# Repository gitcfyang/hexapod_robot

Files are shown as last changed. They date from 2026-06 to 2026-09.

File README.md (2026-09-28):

# Hexapod Robot

六足机器人，基于 Raspberry Pi Pico (RP2040)。18 路数字舵机（2× PCA9685）、
BNO055 IMU 自动调平，支持 ELRS CRSF / PS2 手柄 / USB 三种输入。

## 特性

- 控制循环（默认 100Hz，运行期可调 50~200Hz）+ 实时 IK 解算；四种步态
  （三角 6/8、波纹、波浪）+ 仿生连续变速
- 平衡模式（机身姿态直接控制）+ IMU 姿态补偿自动调平（可选）
- CRSF / PS2 双驱动常编译，`!MODE` 运行时切换，无需焊接插拔；两个驱动共用同一套
  通道与参数（手柄的摇杆/按键在固件里换算到同一套通道号），遥控页 5Hz 实时显示
  协议原值（CRSF 16 通道 172~1811 / PS2 四摇杆 0~255 + 16 按键）
- Betaflight 式「模式」页：解锁/平衡/步态/站立姿态挂在哪个通道、落在哪几档
  （模式矩阵），以及一次性动作用哪组按键（组合键，遥控上按键 = 通道 CH5~CH16），
  全部是运行期参数，`!CFGW` 掉电保持；每行可选「单击触发」（拨一下切换）或按住生效，
  同一套配置对遥控器与手柄都成立 —— 解锁出厂是电平语义（开关拨走即上锁），
  勾上「单击触发」就变回拨一下翻转
- 运动学几何（腿节长度/站高/舵机零位/安装角/机身与足端偏移）是运行期参数，
  网页「几何」页可调，上电时生效
- 电池保护（过压/低压/过放自动断舵机供电）、硬件看门狗、I2C 总线自恢复
- 非易失存储：校准参数（18 路 horn_offset + PWM 周期）存 flash 掉电保持，
  事件日志环形记录（BOOT/电池/校准），`!SAVE` / `!LOG` / `!LOGC`
- 运行时参数：92 项（步态行程/阈值/开关/方向取反/IMU 手感/通道映射/模式矩阵与
  组合键/几何/控制周期/外设所有权与波特率/引脚归属）可在网页或串口在线调整，`!CFG` / `!CFGR` /
  `!CFGW`，改完即生效（几何组例外：重启后生效）、`!CFGW` 存 flash 掉电保持
- 板载预留接口在线可控：直流电机 ×2（仅调速，无方向脚）/ 蜂鸣器 / 双 LED /
  外部 UART0（GP0/GP1）/ 外部 I2C 或 ADC（GP26/27）/ PCA9685 空闲 14 路 PWM，
  串口命令 + 网页「外设」页（外设尚未接线，详见 [STATUS.md](STATUS.md)）
- Betaflight 式「端口」页：一行一组引脚选用途 —— 复用脚（UART0 / 输入 UART1 /
  电机 GP2-3 / 足端检测 GP16-21 / 外部排针 GP26-27）改功能下拉即写参数；
  GP23/24/29 这三脚在板上没往外引（Pico 模块内部分别连着 SMPS 模式 / VBUS 检测 /
  VSYS 检测），页面照常能切输入输出、用 `!GPO` 给电平，但只当调试口用；
  固定脚只读。状态列报引脚此刻的实测电平（`!PORTS` 轮询），
  参数与硬件对不上时看得出来
- TCP/IP 远程访问：串口控制台内置 TCP 桥接（多客户端广播 + 命令反向下发），
  可 headless 运行，配 `tools/tcp_monitor.py` 远程操作
- PCB 设计、Gerber、全项目 BOM、机械 STEP 全部开源（见 [hardware/](hardware/)）

## 快速开始

```bash
cd pico/build && make -j$(nproc)
```

编译产物 `hexapod_pico.uf2` 拖入 Pico 的 USB 盘即烧录；Linux 下可免按键：
`picotool load -f -x build/hexapod_pico.uf2`（运行中的固件会被软复位进 BOOTSEL）。
调试控制台：`python3 tools/serial_console.py`（自动连接、断线重连）。
网页配置台（同一个页面，两种开法）：

**直连 —— 板子插在你自己电脑上，零安装**：Chrome/Edge/Opera 打开
<https://gitcfyang.github.io/hexapod_robot/> → 点「连接」→ 浏览器弹串口选择器选中
Pico，页面直接读写 USB 串口（Web Serial），没有本地服务、不用下载任何东西。
参数/端口/校准/日志都在这一条路上；改动推上 main 后 Pages 自动发布（约 10 分钟生效；
仓库首次要去 Settings → Pages 把 Source 选成 GitHub Actions，一次性）。
**备选：双击本地那份 [index.html](tools/webconfig/index.html)** —— 同一个页面、同样的
功能，不用等发布也不联网，只是得自己把文件拿到手（Chrome 把 `file://` 也当安全上下文，
串口照常可用）。Safari 不支持，Firefox 需 151+；浏览器不给弹串口选择器时换下面「本地服务」那套。
⚠️ **烧固件不在直连里** —— uf2 拖进 Pico 的 USB 盘照旧。

**本地服务 —— 板子插在别的机器上，或要烧固件**：`python3 tools/webconfig/run.py start`
→ 浏览器开 `127.0.0.1:8080`
（同一个脚本还有 `stop`/`restart`/`status`/`logs`，重启＝先终止旧进程再起新的；
它只管这个 HTTP 服务，不碰串口桥。Linux 侧 `tools/webconfig/run.sh start` 是它的包装，
不经脚本直接跑 `python3 tools/webconfig/server.py` 也一样。
跨平台的是 `run.py`（Windows/WSL 同样可用），但串口桥 `serial_console.py` 本身是 Linux-only，
Windows 只适合当浏览器一端、用 VSCode 端口转发连过来。
打开先是**开始页**：只看硬件是否在线、机器人跑的是什么固件，并可一键烧录新固件；
检测到设备后点「连接」才进调试页 —— 状态: 实时电压/I2C/IMU/舵机角度 · 参数按功能
分页（步态/姿态/几何/遥控/模式/电源/平衡/控制/外设/端口）: 滑条改参数并写 flash ·
几何: 腿长/站高/舵机零位/安装角/偏移（重启生效）· 遥控: 输入源切换 +
通道实时显示 · 模式: 解锁/步态/站姿的模式矩阵 + 组合键 + 单击触发 + 实时状态徽标 ·
控制: 舵机供电开关 + 行走/转向/步态/抬腿按钮 + 两块 PCA9685 的
PWM 周期滑条 · 外设: 电机/LED/蜂鸣器/外部 UART/外部 I2C+ADC/空闲 PWM 控制卡 ·
端口: 每对引脚的功能选择（复用脚改用途、GP23/24/29 切输入/输出并给电平、固定脚只读），
外加引脚实测电平 · 校准: 逐舵机定机械中心（选中格子 → 滑条转到中立位 → 设为中心），
再是舵机走查/保存/总线扫描 + 电压标定（万用表实测值 → 分压比）+ IMU 校准
（校准等级显示 / 复位重标）· 日志: 串口日志 + 命令输入；拔 USB、桥接断开或点
「断开连接」都会回到开始页，细节见 [STATUS.md](STATUS.md)）。
连接前可勾「调试时允许遥控器控制」—— 不勾（默认）则调试期间遥控器只上报通道值，
机器人只听网页命令；机器人自己会在失去心跳 6s 后放回遥控器（网页挂了不会锁死）。
远程访问：控制台默认同时开 TCP 桥接（`127.0.0.1:7100`），
另开终端 `python3 tools/tcp_monitor.py` 即可远程收发命令（可多开）。
**网页给别人用**：板子在对方手边，让他开上面那个 Pages 直连页就行（你这边不用做任何事）；
板子插在你这台机器上、要让别的电脑看，才需要下面这套 —— 服务默认只监听 `127.0.0.1`（本机浏览器），要让别的电脑连，
起服务时给监听地址 —— 同一局域网 `run.py start --host 0.0.0.0`，
任何设备开 `http://<这台机器的IP>:8080`；跨网络又不想挂公网，就用 Tailscale
（本机已在跑）等私有网，`run.py start --host <tailnet IP>`，加入同一网络的设备
直接开 `http://100.x.y.z:8080`，两个网卡都不通的路由不会经过它。
⚠️ 这个服务没有鉴权：能连上网页的人就能解锁、驱动 18 路舵机、烧固件。所以
「任何浏览器都能开」的公网隧道要么别开，要么先加鉴权（TODO，见 STATUS）。
（直连那条路不涉及这个问题：页面虽在公网，但只有把板子插在自己电脑上、并在浏览器
弹窗里亲手选中串口的人才能操作它 —— 指令不过任何服务器。）
串口桥（7100）保持只听本机，别跟着放开。

## 硬件概览

- MCU: Pico (RP2040) · 舵机: 18× 双轴数字舵机, 2× PCA9685 · IMU: BNO055 (I²C 0x29)
- 电池: 2S 18650, GP28 ADC2 分压 47/377 (330k+47k)，低压/过压/过放自动断舵机供电（双路AO4407A实现）
  （`batt_check` 参数默认 0，待新板实测分压后启用；分压比可在网页校准页按万用表实测值一键重标）
- 足端微动开关 ×6 · 无源蜂鸣器 · 双 LED · 直流电机 ×2（调速）
- 预留未接线：外部 UART0（GP0/GP1）· 外部 I2C 或 ADC（GP26/27）·
  PCA9685 空闲 14 路 PWM（编号与舵机通道不相交，可与舵机同批输出）
- 完整 GPIO 分布、电池保护分级行为: 见 [STATUS.md](STATUS.md) 硬件章节

## 机架

本项目机架使用 18× **双轴舵机**（STEP 模型见 [hardware/mechanical/](hardware/mechanical/)）。
低成本替代可用 3D 打印方案 [MakeYourPet/hexapod](https://github.com/MakeYourPet/hexapod)
(MIT，MG996R 单轴舵机)：移植本固件只需改腿节长度、舵机零位、安装角等几何参数
（网页「几何」页或 `!CFG`，重启生效，详见 [STATUS.md](STATUS.md)），
IK 与步态算法本身无需修改（同为 3 关节腿）。

## 控制

| 模式 | CH1 | CH2 | CH3 | CH4 | CH5~CH8 |
|---|---|---|---|---|---|
| 正常 | 左右平移 | 前进/后退 | 机身高度 | 原地转向 | 解锁 / 步态 / 站立姿态 / 平衡模式 |
| 平衡 | 机身横滚 | 机身俯仰 | 机身高度 | 机身偏航 | 同上 |

表中 CH1~CH8 是**默认**映射，全部可在网页上改（「遥控」页改摇杆通道、「模式」页改
开关）：摇杆通道填 `0~19`（`!CFG ch_fwd <0-19>`），开关是「通道 + 低/中/高档位」的
模式矩阵。**遥控器与手柄共用这一套** —— 手柄的摇杆与按键先换算成同一套通道号，
再走同一段映射，改完立即生效、`!CFGW` 掉电保持。
每行还能勾「单击触发」：不勾 = 停在激活区间内才生效（解锁出厂如此），
勾上 = 进入区间时动作一次（解锁/平衡翻转，步态/站姿选一次）。手柄的一次性动作
（切步态/站姿、抬腿、急停）在「模式」页的组合键表里，遥控上按键即通道 CH5~CH16。
出厂默认方向取反全 0；若某个方向与手感相反，翻「遥控」页的「方向取反」
（如 `!CFG inv_str 1`），不要改通道号。
输入源由参数 `input_mode` 决定（`!MODE crsf|ps2` 或网页按钮切换，`!CFGW` 掉电保持），
`INPUT_CONTROL_MODE` 只是出厂默认值。PS2 完整按键映射见 STATUS.md。

## 结构

```
hexapod_robot/
├── pico/        # RP2040 固件 (HAL 结构: Inc/Src)
├── tools/       # 串口控制台 serial_console.py (+ TCP 桥接) · IK 仿真 ik_gait_debug.py
│              # webconfig/ 网页配置台 · tcp_monitor.py 远程客户端 · 无硬件测试
├── hardware/    # PCB 设计/机械/BOM (见 hardware/README.md)
├── README.md
└── STATUS.md    # 固件细节: GPIO/参数/步态/调试/电路保护
```

## 状态

> ⚠️ **项目仍在持续开发中，功能和接口可能随时变动。**

## License

固件: GNU GPLv3（见 [LICENSE](LICENSE)）。硬件文件授权另行约定（见 [hardware/README.md](hardware/README.md)）。

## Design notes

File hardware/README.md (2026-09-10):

# 硬件文件

六足机器人的 PCB 设计与机械结构。硬件接口说明见 [../STATUS.md](../STATUS.md) 硬件章节。

## PCB (v2, 2026-09)

- [pcb/source/](pcb/source/) — 立创EDA 专业版工程（原理图 + PCB）
- [pcb/schematic.pdf](pcb/schematic.pdf) — 原理图 PDF（网页可直接预览）
- [pcb/board/gerber/](pcb/board/gerber/) — 打板文件（zip 打包，直接上传嘉立创）
- [pcb/board/assembly/](pcb/board/assembly/) — 贴装 BOM + 坐标文件（SMT 贴片用）

设计要点：2S 18650 直供舵机轨（2× AO4407A 门控，上电默认断电）；VBAT 入口
SMBJ18A + 每颗 MOSFET 两端 SMBJ12A；I2C 总线 TVS + BNO055 stub 串阻 + VDD 限流；
电池分压 330k+47k 入 GP28 ADC2。保护设计背景见 STATUS.md「电路保护建议」。

## 物料清单 (BOM)

- [bom/hexapod_bom.md](bom/hexapod_bom.md) — 全项目物料（含购买链接，网页可点击）
- [bom/hexapod_bom.csv](bom/hexapod_bom.csv) — 同名数据（链接为 URL 文本，供程序处理）

## 机械结构

- [mechanical/hexapod.step](mechanical/hexapod.step) — 整机架装配体（18× 双轴舵机版）
- 低成本 3D 打印替代机架：见根目录 README「机架」

## 待补

- 板子 3D 渲染图 / 实物照片（pcb/images/）
- 3D 打印件 STL
- 接线图 / 装配说明（docs/）

## 许可

固件为 GPLv3（根目录 LICENSE）。PCB 与机械文件建议另行采用
**CERN-OHL-S 2.0** / **CC-BY-SA 4.0**（硬件设计不适用 GPL）。

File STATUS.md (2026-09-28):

# 六足机器人 固件状态

## 硬件
- 硬件设计文件: [hardware/](hardware/) — PCB 源工程 (立创EDA) / 原理图 PDF /
  Gerber / 贴装 BOM+坐标 / 全项目 BOM (含购买链接) / 机械 STEP
  (说明见 hardware/README.md)
- MCU: Raspberry Pi Pico (RP2040)

### GPIO 分布 (PCB 定版)

| GPIO | 功能 | 说明 |
|:---:|---|---|
| GP0 | 外部 UART0 TX | 预留: 上位机/传感器扩展 (`uart0_en=1` 后启用) |
| GP1 | 外部 UART0 RX | 预留: 上位机/传感器扩展 (收行以 `[U0]` 转 USB) |
| GP2 | 直流电机 1 | PWM 调速 (10kHz, `!MOTOR 1`), 无方向引脚; `dc_motor_en=0` 释放成 GPIO 输入 |
| GP3 | 直流电机 2 | PWM 调速 (10kHz, `!MOTOR 2`), 无方向引脚; `dc_motor_en=0` 释放成 GPIO 输入 |
| GP4 | CRSF TX | UART1 @420000 baud (串口输入模式下由 `input_baud_serial` 决定) |
| GP5 | CRSF RX | UART1 @420000 baud (同上) |
| GP6~GP9 | PS2 接收机 | bit-bang SPI (DAT/CMD/SEL/CLK) |
| GP10 | 左舵机供电 | 高电平=供电，低压自动断电 |
| GP11 | 右舵机供电 | 高电平=供电，低压自动断电 |
| GP12 | 红色 LED | 报警指示 (与绿 LED 功能分离); `!LED r 0/1`, 所有权见 `led_alarm` |
| GP13 | 无源蜂鸣器 | PWM 方波发声 (`!BUZZ <freq> <ms>`) |
| GP14 | I2C1 SDA | PCA9685 + BNO055 @400kHz |
| GP15 | I2C1 SCL | PCA9685 + BNO055 @400kHz |
| GP16~GP21 | 足端微动开关 | 输入上拉，落地→GND; `foot_sw_en=0` 释放成 GPIO 输入 (读 API 一律报未触地) |
| GP22 | IMU BOOT | 上电高=正常模式，初始化失败自动循环恢复 |
| GP23 / GP24 / GP29 | Pico 板载 | 模块内部分别连着 SMPS 模式 / VBUS 检测 / VSYS 检测 (ADC3), 板上**没往外引**; 端口页 `gpXX_fn`: 0=输入 (默认), 1=输出 (初值低, `!GPO` 写电平)。输入态的电平是模块自己的状态: GP24 读得出 USB 在不在 (=1), GP29 是 200k/100k 分压 (VSYS/3 ≈ 1.7V) 在数字门限之下、**恒读 0** (真机实测)。切输出只当调试口用 |
| GP25 | 绿色 LED | Pico 板载，状态指示; `!LED g 0/1`, 所有权见 `led_heartbeat` |
| GP26 | 释放 | 外部 I2C SDA (**软件位翻转**) 或 ADC0 — 由 `ext_i2c_mode` 选 |
| GP27 | 释放 | 外部 I2C SCL (**软件位翻转**) 或 ADC1 — 由 `ext_i2c_mode` 选 |
| GP28 | 电池 ADC (ADC2) | 分压 47/377 (330k+47k)，2S 18650 |
- 舵机: 18路, 2× PCA9685
  - **PCB 定版地址**: 0x40 (ADDR=GND) = 左腿组 ID 9-17; 0x41 (ADDR=VCC) = 右腿组 ID 0-8
  - **物理通道 (LEDn)**: 左板 0x40 从前至后 LED7~LED15 (LF 7/8/9, LM 10/11/12, LR 13/14/15)
    右板 0x41 从前至后 LED8~LED0 (RF 8/7/6, RM 5/4/3, RR 2/1/0)
  - 映射表: `pca9685_servo_to_channel()` + `pca9685_get_board_idx_by_addr()` (hexapod_i2c_protocol.c)
- PCA9685: I²C1 GP14(SDA)/GP15(SCL) @400kHz, 内部上拉
  - **⚠️ PCA9685 必须供 3.3V**（不可 5V！5V I2C 上拉会击穿 RP2040 的 GPIO）
  - 2026-06 曾因 PCA9685 模块 5V I2C 上拉倒灌，烧坏 2 块 Pico 的 GP2/GP3
  - 保护: 总线 TVS 钳位 + BNO055 stub 串 100Ω 限流电阻
    (主总线走线保持完整, 内部上拉保留作后备, 与外部保护不冲突)
- PWM: 数字舵机 ~105Hz (周期 9500µs), 两片 PCA9685 周期/频率独立可标定
- 接收器: ELRS CRSF, UART1 GP4/GP5 @420000bps
- PS2 接收器: bit-bang SPI GP6~GP9 (DAT/CMD/SEL/CLK), 与 CRSF 双驱动常编译, !MODE 运行时切换
- IMU: BNO055 9轴姿态传感器, I²C1 GP14/GP15 (共享), 地址 0x29 (!I2C 实测确认)
  - BOOT 引脚: GP22 — 固件上电驱动高 (正常应用模式), I2C 初始化失败自动循环 BOOT 恢复 (3 次)
  - INT 引脚: 未引出 (本板芯片 SW rev 0x0308 不支持 BSX DRDY 中断, 需 ≥0x0314;
    100Hz 轮询足够, 无需 INT 引脚)
  - imu_enabled 参数默认 0 (姿态补偿代码就绪, 待新板实测 IMU 后启用) —
    运行期开关: `!CFG imu_enabled 1` 立即生效, `!CFGW` 才掉电保持
  - 安装方向: 正常安装 (芯片朝上): Xc=rX(前) Yc=rZ(右) Zc=rY(上)
    - 平放 chip pitch≈0, 映射: robot_roll=+(pitch), robot_pitch=+roll
    - 符号宏 IMU_ROLL_SIGN=-1 / IMU_PITCH_SIGN=+1 (实测验证中)
  - 保护: VDD 串电源限流电阻 (防闩锁拖垮 3.3V 轨) +
    I2C stub 各串 100Ω (SDA/SCL, 靠近器件引脚)
  - ⚠️ NDOF 校准 (sys/mag=0) 完成前姿态数据不可靠, 补偿可能注入错误偏移
- 蜂鸣器: GP13 无源蜂鸣器 (PWM 方波, notes 数组=频率 Hz, 0=休止)
- 双 LED: GP25 绿色 (状态), GP12 红色 (报警) — 功能分离
- 直流电机: GP2/GP3 (PWM 调速 10kHz, 占空比 0~1000×0.1%)
- 舵机供电: GP10 左/GP11 右 (高电平=供电)
  - **上电默认断电, 由 ARM 解锁开关控制**: 解锁→开供电+输出 PWM; 锁定→停 PWM+断供电
  - 低压/过压自动断电; 电压恢复后仅在解锁状态下重新供电
  - !C/!PER 校准模式进入时强制开启供电 (直接驱动舵机)
- 电池: GP28 ADC2, 分压 47/377 (R1=330kΩ, R2=47kΩ), 2S 18650
  - 330k 高串阻限制电压尖峰流入 ADC 的电流, 与齐纳钳位/TVS 配合更安全;
    满电 8.4V→ADC 1.05V
  - 阈值: 过压 8.8V / 警告 7.0V / 截止 6.6V / 恢复 7.3V
  - 行为分级:

    | 电压 | 状态 | 行为 |
    |:---:|------|------|
    | > 8.8V | 过压 | 红灯常亮 + 蜂鸣, 断开两路舵机供电 (误接 3S/电源故障) |
    | 7.3V~8.8V | 正常 | 绿灯运行 |
    | 7.0V~7.3V | 低压警告 | 红灯 2Hz 闪烁, 可继续运行 |
    | 6.6V~7.0V | 严重低压 | 红灯快闪 + 蜂鸣 |
    | < 6.6V | 过放保护 | 红灯常亮 + 蜂鸣, 断开两路舵机供电 |
    | ≤ 3.0V | **未接电池 (USB 供电)** | **正常, 跳过保护** (见下) |
  - 上电先检测电压再开舵机供电; 运行时每 `batt_interval_ms` (默认 1s) 监测
  - **未接电池不是故障**: 分压抽头被 R2 拉到 ~0mV, 按"低于截止"处理会假报过放
    并停机 —— 而 USB 供电调试正是最常用的台面场景。判定见 `hal_battery_state()`
    (`pico/Src/hexapod_hal_pico.c`), 三态 OK/ABSENT/FAULT:
    - 电压 ≤ `batt_absent_mv` (默认 3000) → ABSENT; 需连续 3 次采样确认 (去抖)
    - 已在截止区且在下降 → 电压还没落定, 维持上次状态再看一轮; 落定了才判 FAULT。
      拔电池/拔电源后储能电容经分压电阻放电, 电压从 8.4V 穿过 6.6V 截止区衰减到 0,
      没有这条规则会在衰减途中误停机。判据取"是否还在下降"而非"降得多快": 衰减
      慢下来后单次跌幅会小于任何固定阈值, 而那时电压仍在截止区里, 快速判据会漏判
      成过放 —— 真过放则是掉到某个值然后停住, 两种衰减速度一视同仁。
    - "是否还在下降"看 4 次采样 (`BATT_TREND_LEN`) 的滑动窗口: 窗口内最高值比当前值
      高出 `BATTERY_SETTLE_MV` (100mV) 就算仍在下降。取最高值而非最低值 —— 电压
      单调下降时窗口最低值就是上一次采样, 等于只跟上一次比, 窗口白留。真衰减每采样
      多欠一截, 纹波只在均值附近摆, 摆到波谷时会被当下降, 但下一采样就回波峰侧,
      至多推迟一两次。等待的下界是 `batt_absent_mv`: 掉到 3.0V 以下一定给出结论。
    - 只有 FAULT 才停机; 状态迁移时打印一次, 不逐次刷屏。
  - ⚠️ batt_check 参数默认 0, 待新板实测分压电路后改回 1
    (运行期可切: `!CFG batt_check 1`; 开机自检的等待循环里有退出通道,
    否则误设 0 会卡在自检里出不来)
  - 分压比是参数 `batt_ratio_milli` (默认 8134 = 8.134, 理论 377/47 = 8.021):
    单点标定 (2026-09-27, `!BATT` 对万用表: 8.37V vs 引脚 1029mV)。读数偏低约
    1.4%, 来自 330k‖47k ≈ 41k 源阻抗令 ADC 采样保持电容充电不足, 加上电阻容差
    与 3.3V 参考自身偏差 —— 换板/换稳压方案后需重新标定; 偏低的读数是让截止
    提前, 属安全侧。
  - 重标定不需要改固件: 网页校准页的电压卡就是这条式子的入口 —— 填万用表实测值,
    页面按 `实测 mV ÷ ADC 引脚电压` 算出新的 `batt_ratio_milli` (引脚电压与分压比
    无关, 是基准量) 并下发, 再按「保存到 Flash」掉电保持。
- 外部扩展: GP0/GP1 预留 UART0 (上位机/传感器), GP26/GP27 释放
  - GP26/GP27 可作两个独立 ADC (ADC0+ADC1: 电流检测/距离传感器/电池温度等),
    或第二路 I2C (SDA=GP26, SCL=GP27, 上位机传感器扩展/外置 ADC/ToF),
    两引脚相邻走线方便; 当前实现只做这两用, 二者互斥
  - **外部 I2C 是软件位翻转而非硬件控制器**: RP2040 的 GPIO 功能表中 GP26/27 只
    能映射到 I2C1, 而 I2C1 已归 PCA9685+BNO055 (GP14/15) 独占 —— 想用硬件 I2C
    就得把内部总线挪走或让两路共用控制器。开漏模拟只需两个 GPIO +
    `busy_wait_us` 延时 (≈50kHz), 与 I2C1 完全独立, 是这里唯一不牵动既有总线的做法
  - 引脚功能 (UART0 / I2C / ADC) 由参数在运行期切换, 见「预留外设」
  - CMake 已关闭 stdio UART (pico_enable_stdio_uart=0), 调试输出仅走 USB CDC,
    保证 GP0/GP1 空闲给外部 UART 用
- 足端传感器: 6× 微动开关 GP16~GP21 (输入上拉，开关→GND 闭合读低)
- 腿: coxa=45mm, femur=75mm, tibia=120mm (默认值; 已是运行期参数, 见「关键参数」)
- 舵机零位: FEMUR_SERVO_ZERO=450, TIBIA_SERVO_ZERO=900
- 底板: coxa基座高出底板25mm
- ⚠️ I2C 总线上存在未知设备 0x70 (!I2C 全扫描发现, 待确认是否预期)

## IK 公式 (hexapod_ik.c)
```
S_c = ±(atan4(z,x) - COXA_ANGLE) + horn
d   = √(x²+z²) - Lc
a   = √(d²+y²)
S_t = ±(TIBIA_ZERO - acos((Lf²+Lt²-a²)/(2·Lf·Lt))) + horn
S_f = ±(acos((Lf²+a²-Lt²)/(2·Lf·a)) - atan4(y,d) - FEMUR_ZERO) + horn
     右腿 invert(取反), 左腿不变
```

## 关键参数 (几何 = geo 组运行期参数, 网页「几何」页 / `!CFG`, **重启后生效**)
- 站立: INIT_Y=50mm (赋给各腿 init_pos_y; core.c:269 target_foot.y = init_pos_y + gait_pos.y)
- 机身高度不以 init_pos_y 表达, 而由 body_pos.y 在 IK 层叠加 (ik.c:248 relative_pos.y = target_foot.y + body_pos.y)
- COXA_ANGLE: RR=1350, RM=900, RF=450 (**左腿取反** → -1350/-900/-450)
- FOOT_DX: RR=-113, RM=0, RF=113 (**不镜像**: 左右腿同值)
- FOOT_DZ: RR=113, RM=160, RF=113 (**左腿取反**)
- BODY_OFFSET_X: RR=-104, RM=0, RF=104 (**不镜像**); BODY_OFFSET_Z: 63/79/63 (**左腿取反**)
- 镜像规则写在 `hexapod_config.h` 的宏里 (如 `#define COXA_ANGLE_LR (-(g_params.coxa_angle_rear))`),
  与参数化之前的字面量逐字对应 —— 改参数只需改一份, 左右腿由宏负责取反
- 步长: TRAVEL_MAX_FORWARD=150mm, STRAFE=110mm, TURN=70mm
- 抬腿: LIFT_HEIGHT 5-60mm
- 机身高度调节: BODY_HEIGHT_RANGE_MM=±90mm

上面几项里, 腿几何那几项 (腿长 / INIT_Y / 股-胫舵机零位 / COXA_ANGLE / 足端与机身
偏移) 在 `hexapod_config.h` 里已全部改成 `#define X (g_params.x)` (默认值
保留为 `X_DEFAULT`), `hexapod_get_default_config()` 与 IK 的调用处一个字都没改。
**上电时应用一次**: `params_load()` 早于 `robot_init()`, 所以 flash 里的值直接参与
构造六条腿的 leg_configs; 运行中改参数只写进 RAM 与 flash, 重启才生效。
步长 / 抬腿 / 机身高度那三项属于 motion / stance 组, 改完即生效。

## 仿生连续变速
- 摇杆幅度连续映射到步态周期
- GAIT_PERIOD_MAX=190ms → MIN=50ms
- 低摇杆 = 短步长 + 低频率, 高摇杆 = 大步长 + 高频率
- 速度控制只用前进/平移/转向三个摇杆, 开关通道不参与 (开关去模式矩阵)

## 控制链路
```
两协议共用的输入层 (CRSF / PS2 → 统一通道 0~3 摇杆 + 4~19 开关):
  正常模式:
    摇杆 → 映射 → 死区 → 指数 → 取反 → 仿生连续变速 → 子步态插值(每步态 100 子步)
    → [IMU body_rot_offset 取反叠加] → IK → servo batch → I²C (PCA9685) → PWM

  平衡模式:
    摇杆 → 映射 → 死区 → 指数 → 取反 → body_rot + body_pos.y 直接映射
    → [IMU body_rot_offset 取反叠加] → IK (standing) → servo batch → I²C → PWM

  两条路的开关 (解锁/平衡/步态/站姿) 都由模式矩阵与组合键给出, 见「输入控制模式」
```

## 平衡模式 body_rot 坐标
- X=前 Y=上 Z=右 (右手定则)
- body_rot.x = Roll 横滚 (Rx, 绕 X 前进轴, 摇杆 CH1)
- body_rot.y = Yaw 偏航 (Ry, 绕 Y 垂直轴, 摇杆 CH4)
- body_rot.z = Pitch 俯仰 (Rz, 绕 Z 左右轴, 摇杆 CH2)
- 三轴均取反，使摇杆方向与机身倾斜方向直觉一致
- 旋转顺序: Ry(Yaw) → Rx(Roll) → Rz(Pitch)

## IMU 姿态补偿
- BNO055 9轴 IMU, 与 PCA9685 共享 I²C1 (GP14/GP15), 地址 0x29
- 工作模式: NDOF (9-DOF 融合), 100Hz 欧拉角输出
- 补偿通道: body_rot_offset (Roll/Pitch 取反, Yaw=0 不补偿)
- 叠加点: compute_leg_ik() 中 effective_body_rot = body_rot + body_rot_offset
- 启用: `!CFG imu_enabled 1` (默认 0, 待新板实测后启用; 关掉时 body_rot_offset
  会归零, 不会残留上次的倾角)
- 增益: IMU_COMPENSATION_GAIN (×10, 默认 10=1:1 直接补偿)
- 驱动: bno055.h/c, 通过 hal_imu_init()/hal_imu_read() 封装
- 原始值: `!IMU` 除融合结果外还打印 加速度/陀螺/磁力/温度 的**未换算 LSB**
  (`accel:`/`gyro:`/`mag:`/`temp:` 四行, 单位标在行尾)。驱动从未写过 `UNIT_SEL`,
  即 BNO055 默认单位 —— 加速度 0.01 m/s² (不是 mg)、陀螺 1/16 dps、磁力 1/16 uT、
  温度 1°C 且 int8 有符号, 并且是**芯片温度**不是环境温度。这四行只被 `!IMU`/`!IMUR`
  打印 (每秒一次的诊断读, 在主循环而非中断里); 它**不经过** `hal_imu_read()` 与
  `imu_data_t`, 20ms 控制回路零改动。网页状态总览的曲线吃这四行 + `last:` 的欧拉角
- 校准: 标定值由 BNO055 自己维护 (NDOF 连续自校准, 体现为 `CALIB_STAT` 的
  sys/gyr/acc/mag 四级) —— 固件只做**显示与清空**: `!IMU` 打印等级, 网页校准页
  实时显示。`!IMUR` = 写 `SYS_TRIGGER.RST_SYS` 整芯片复位后重新初始化
  (`hal_imu_init`, 含 BOOT 引脚重试), 清空标定值让机器人重走一遍: 平放几秒
  sys/gyr 回 3 (此时的 Roll/Pitch 就是水平零点), 六个面各朝上停一会儿 acc 回 3,
  磁力计要在原地转圈。复位约 0.7s 内主循环停摆, 所以行走中拒绝; 复位后驱动
  状态作废, 姿态读数短暂无效属正常。
- 容错: 传感器未检测到时打印警告, 固件正常运行 (无补偿)
- 读挂掉的现场签名 (2026-09-28 真机实测, v0.4.0): `!IMU` 只剩 `available:` + 冻结的
  `last:` 两行 —— 那几个**读成功才打印**的行 (calib / INT / SW rev / 原始值) 一起消失,
  而 `last:` 由控制回路每 `loop_ms` 更新, 跨分钟一字不变 = 控制回路那个读也停了
  (开着补偿时的表现: 姿态曲线停住 + 机身按一个旧倾角一直补偿)。同一次卡住里
  `!I2C q` 给出判据: 两块 PCA9685 正常应答、`Bus idle SDA=1 SCL=1` (总线空闲),
  唯独 `BNO055 0x29: NOT FOUND` —— **芯片不应答它自己的地址**, 既不是总线电气问题,
  也不是驱动/外设卡死; 紧接着再问一次 `!IMU` 仍缺那八行, 说明 `i2c_init` 治不了它。
  实测持续几秒到几分钟后**自行恢复** (监视器 25 分钟里 730 次中 1 次, 卡了 4s)
- IMU 读看门狗 (2026-09-28 加): 控制回路每周期推一次, `!IMU` 命令里再推一次 (校准
  模式下控制回路提前返回, 光靠它没人修)。连续失败 ≥20 次 (10ms 回路 ≈200ms) → I2C
  总线恢复 (补时钟 + STOP + i2c_init, 便宜, 治"SDA 被器件拉死"那种); 仍失败 10s →
  重新初始化 BNO055 (靠 BOOT 引脚复位芯片, **会清空标定值** —— 芯片不应答时只有它
  能拉回来, 阈值取 10s 是为了让几秒级的自愈不动校准)。已解锁时只做总线恢复:
  重新初始化阻塞主循环约 4s, 不能边走边干。每一步都打印 `[IMU]` 行 (原来整段卡住
  是**全静默**的), 且 `!IMU` 在有失败时多一行 `fail: 连续 N 次 / 累计 M 次`
- 频繁卡死的那个来源已定位并修掉 (2026-09-29): 网页每 3s 的 `!I2C q` 轮询会让
  控制回路连丢约 200ms 读数 —— 完整模仿网页轮询 141s 复现 21 次 (间隔恒为 3s 的
  整数倍), 零轮询 / 只轮询 `!IMU` 各 180s 都不复现; 23 次恢复里没有一次 SDA 被
  从设备拉死, 所以是**外设卡**不是器件卡。根因是检测块末尾那段电平诊断: 它把
  SDA/SCL 切成 `GPIO_FUNC_SIO` 再切回, 而切走的那一瞬间 I2C 外设自己的输入变 0
  (IO mux 只把 pad 输入接给被选中的功能), 外设把这个当成总线事件锁住, 直到有人
  `i2c_deinit` + `i2c_init` 才清掉 —— `pca9685_i2c_recover()` 正是这个顺序, 所以它
  每次都救得活。现在改读 IO bank 的 `INFROMPAD` (与 FUNCSEL 无关的 pad 原文),
  引脚全程留在 I2C 功能上; 量电平前先等 2ms 让上拉把线拉回空闲高电平 (事务刚结束
  就测会读到一半 1 一半 0 的假电平, 这个坑单独踩过一次)。修复后 3×180s / 180 次
  轮询零卡死, `Bus idle` 读数 60/60 恒为 1 1
- 开放问题: 芯片**自己不应答地址**那一类 (上面 09-28 的现场签名), 根因仍未定论
  (候选: 芯片内部状态机被某次事务打断后卡住、时钟拉伸的边界时序、供电瞬间跌落),
  自那以后没再复现过 (监视器 25 分钟里 730 次中 1 次)。看门狗只管"拉回来"和
  "留下现场": 再遇到时看 `[IMU]` 那几行 + `!I2C q` 的 `Bus idle` 电平与
  `BNO055 0x29` 是否 NOT FOUND, 就能区分"芯片不应答"还是"SDA 被拉死"
- 坐标映射: 芯片朝上安装, Xc=rX(前) Yc=rZ(右) Zc=rY(上),
  BNO055 Pitch(Xc) → Robot Roll(rX), BNO055 Roll(Yc) → Robot Pitch(rZ)
  (具体正负号取决于 IMU 安装方向, 在 hal_imu_read() 中调整)

### IMU 安装位置分析 (右前方, 偏离几何中心)

- 现状: IMU 位于机身右前方, 重新布局也难做到几何中心 (空间等限制)
- **结论: 影响很小, 当前功能无需处理; 位置问题 << 减振/磁干扰问题**

**角速度 / 姿态角 — 与位置完全无关:**
- 刚体上任意一点的角速度都相同, BNO055 姿态融合 (陀螺积分 + 重力/磁航向修正)
  基本不受安装位置影响 — roll/pitch/yaw 测量值不随位置偏移

**加速度计 — 受位置影响, 但量级可忽略:**
- 偏离旋转中心 r 处会多测到两项 (r≈10cm 估算):

  | 项 | 公式 | 场景估算 |
  |---|---|---|
  | 向心加速度 | ω²·r | 原地转向 90°/s → ~0.03g, 可忽略 |
  | 切向加速度 | α·r | 机身晃动 ±3°@2.5Hz → 峰值 ~0.13g, 瞬时误差几度 |

- 切向项只在机身晃动瞬间出现, 频率与步态相同 (2~3Hz) — NDOF 融合内部
  低通滤波后大部分被滤除; 误差为振荡型, 不累积漂移
- 伺服振动经 PCB 传导的噪声通常比位置误差大一个量级

**对各功能的影响:**

| 功能 | 影响 |
|---|---|
| 当前调平补偿 (Roll/Pitch) | 无感, 不处理 |
| C2 撞击检测 (高G) | 撞击为几个 g 量级, 位置误差可忽略; 换位置后重调阈值 |
| D2 滑移检测 | 唯一真正受影响 — 需要杠杆臂修正 |

**对策 (按优先级):**
1. **当前: 什么都不做** — 误差 < 噪声, 修正的复杂度收益比极低
2. **下版 PCB 优先事项**: ① 减振安装 (泡棉/硅胶垫, 收益最大) ② 远离舵机
   大电流走线 (磁干扰影响航向, 比位置问题严重) ③ 位置尽量靠中 (非必需,
   右前方完全可接受)
3. **将来做 D2 滑移检测时**: CAD 量取 IMU 相对几何中心的偏移矢量 r,
   用陀螺数据 (BNO055 直接输出角速度) 做软件杠杆臂修正:
   `a_body = a_meas − ω×(ω×r) − α×r`, 几行代码, 到那时再加

## PWM 校准
- 用 PWM_PERIOD_US (每板实测周期) 直接计算脉宽计数值
- 不依赖 PCA9685 振荡器精度
- `pulse_to_count = pulse_us × 4096 / pwm_period_us`
- **软硬同源**: 周期既是脉宽换算的分母, 也是芯片的刷新频率 —— 硬件频率由同一周期
  换算 (PRE_SCALE = 25MHz/(4096×freq) − 1, 下限 3 → 上限 1000Hz)。两者必须一起改:
  只改软件数学、芯片仍按标称频率跑时, 输出脉宽会整体偏移
- 当前: PWM_PERIOD_US_BOARD0=9500 (0x40 左板), BOARD1=9500 (0x41 右板) ≈105Hz, 已用 !PER 实测标定
- 两块 PCA9685 的换算周期各自独立可设 (g_board_pwm_period_us[2])，用于补偿器件间振荡器差异；
  实测两板标定值恰好相同 (均为 9500)，独立设置有备无患
- 写硬件频率 (`pca9685_set_freq_board`): SLEEP → 写 PRE_SCALE → 唤醒 (保留 AI 位) →
  RESTART; 板子缺席时只记软件值, 初始化或校准记录回放时补写
- I²C 写入失败检测 + 自动重试 + 连续 3 次失败自动总线恢复 (I2C spec 3.1.16)

### !PER 无示波器周期校准
- `!PER` 进入: 6 个 coxa 舵机置中位 (1500µs), femur/tibia 不发送指令, 主循环 IK 暂停
- `!PER0 <us>` / `!PER1 <us>`: 设置左板 0x40 / 右板 0x41 周期, **实时生效** (立即重写 coxa,
  同时按新周期写硬件频率)
- `!PERO 1` / `!PERO 0`: horn_offset 偏移量开关 (默认 ON)
  - ON: 目标位置 = 0 + 各腿 coxa_horn_offset (与机器人运行公式一致, 摆臂到校准后中位)
  - OFF: 纯 1500µs 原始中位
- 校准原理: 配置周期 ≠ 实际周期 → 摆臂偏离正确位置; 调整至摆臂到位即得实测周期
- `!PERS` 重新置位, `!PERQ` 退出并打印最终值 (填入 hexapod_i2c_protocol.h)
- 注意: 固件角度约定 0=中位 1500µs, ±900=极限; angle=900 会被钳位到 2500µs
- 运行时设置函数: `pca9685_set_pwm_period_us()` (限幅 5000~15000µs ≈ 200~66.7Hz)
- 网页「控制」页两块板各一条滑条 (同一限幅), `!SAVE` 后掉电保持

## 控制频率
- 控制循环: 默认 100Hz (CONTROL_LOOP_PERIOD_MS 默认 10ms), **运行期可调** ——
  参数 `loop_ms` (sys 组, 5~20ms 即 200~50Hz), 改完即时生效, `!CFGW` 掉电保持
- 步态时序是**时间戳制** (gait_period 按 ms 算): 改 loop_ms 不改走速, 只改插值平滑度;
  但 `stance_speed` (×100/周期) 与 `stance_step_mm` (mm/周期) 是**每周期量**,
  loop ≠ 10ms 时它们的实际意义会跟着线性缩放 (网页参数行的「?」有注明)
- PCA9685 PWM: 默认 ~105Hz (周期 9500µs), 每板独立可设 (见「PWM 校准」)
- IK 解算: 每周期一次, 每次更新每帧 PWM 都有新角度
- I2C 批量写入: ~1.5ms/板, 两块板占 ~30% 的周期 (10ms 周期下余量 ~7ms)

## 输入控制模式
- 编译期默认输入源: `INPUT_CONTROL_MODE` (hexapod_config.h)
  - `0` = CRSF 接收器 (ELRS, UART1 @420000 baud) — 默认; PS2 驱动同步编译
  - `1` = PS2 手柄 (bit-bang SPI GP6~GP9) — CRSF 同步编译
  - `2` = USB CDC 串口命令 (无遥控器, 无需 UART1)
- 无线电模式 (0/1) 下双驱动常编译, `!MODE crsf|ps2` 运行时切换 —
  一块板子同时接 ELRS 和 PS2 接收器, 无需焊接/插拔即可切换输入源 (2026-08)
- 切换结果同时写进 `input_mode` 参数 (chan 组), 上电输入源由该参数决定:
  `!MODE` 立即生效, `!CFGW` 后才掉电保持。`INPUT_CONTROL_MODE` 只是出厂默认值
- 参数是输入源的唯一真源: 直接 `!CFG input_mode 0/1` 也即时切换 (主循环里
  `hal_input_sync_mode()` 发现不一致就重配), 不需要重启、也不需要走 `!MODE`
- PS2_ENABLED 自动派生 (仅 USB 模式为 0); 已移除 CRSF/PS2 自动检测机制 (AUTO) —
  无人会同时使用两个遥控, 直接选择更简单可预期
- USB 串口命令列表: `!F` `!B` `!L` `!R` `!Q` `!E` `!S` (运动), `!O` (解锁), `!G<n>` (步态), `!M<n>` (站立姿态 -1/0/1), `!T` (平衡), `!U/!D` (抬腿), `!V` (调试), `!C` (校准), `!HO/!HOS` (逐舵机中心), `!P` `!W` `!Z` `!A` (舵机直控), `!PORTS` `!GPO` (端口状态/电平)

### 统一输入层 (hexapod_input.c / .h)

两个驱动只做「把一帧翻译成统一通道数组」, 之后的映射/死区/指数/取反/开关判定
完全同一条路径 —— 参数表里**没有**两套摇杆参数, 遥控页也就没有两摊要维护。

统一通道 id (两协议共用同一套 `ch_*` 参数与同一份模式表):

| id | 含义 | CRSF 来源 | PS2 来源 |
|:---:|---|---|---|
| 0 | 平移/横滚 | `ch_str` 指定的通道 | 右摇杆 ←→ (RX) |
| 1 | 前进/俯仰 | `ch_fwd` | 右摇杆 ↑↓ (RY) |
| 2 | 机身高度 | `ch_hgt` | 左摇杆 ↑↓ (LY) |
| 3 | 转向/偏航 | `ch_turn` | 左摇杆 ←→ (LX) |
| 4~19 | 开关/按钮 | CH1~CH16 原值 | 16 个按键 (按下 = 高) |

- 量程全固件统一为 CRSF 原始值 `172(Min) ~ 992(Mid) ~ 1811(Max)` (标准 11-bit
  编码)。PS2 摇杆 (0~255, 带中位校准) 与按键 (按下 1811 / 松开 172) 在驱动里
  换算成这套值; 换算不出固件。`[CH]` 遥测行 (5Hz: CRSF = 16 通道原值 + 链路 +
  帧计数, PS2 = 四摇杆 + 键位掩码) 按**协议原值**显示, 是遥控页实时面板的数据源,
  被 server.py 解析消费, 不进网页日志面板
- 通道→功能的映射是运行期参数 (chan 组 4 项: `ch_fwd` / `ch_str` / `ch_turn` /
  `ch_hgt`, 填 `0~19`), 改完立即生效。不校验重复映射: 两个功能填同一通道时,
  两边会被同一个摇杆同时驱动 (页面把重复的功能名并排显示在同一格)
- 摇杆处理顺序: 映射 → 死区 (`ch_deadband`) → 指数 (`expo`) → 取反
  (`inv_fwd` / `inv_str` / `inv_h` / `inv_turn`, 按**功能**不按通道 —— 换通道后
  方向反了应该翻取反, 而不是改通道号)。出厂默认全中性 (取反全 0, 指数 0)
- 机身高度两种输入方式, 由参数 `height_integrate` 决定:
  - `1` (默认) = **积分/速率**: 摇杆是升降速率, 回中保持当前高度 (弹簧摇杆的
    用法); 满行程约 2 秒走完全量程, 摇杆幅度越大变化越快。`h_deadzone` 只管
    这一路 (比运动死区大, 防中心抖动被积分成漂移)
  - `0` = **线性/绝对**: 摇杆位置直接等于高度偏移, 中位即原高度 (遥控器旋钮的
    经典用法)
  - 运行中切换不跳变: 积分器用当前值接续
- 输入源切换时调 `hexapod_input_reset()` 清积分器与按键沿, 否则切回来第一次
  按键会被当成「一直按着」而误触发
- 每个控制周期都会重写 `gait_type` / `stance_mode` (模式矩阵的电平语义), 所以
  `!G` / `!M` 这类一次性命令会被下一帧覆盖 —— 与「开关一直按着」的行为一致;
  遥控门 (`!RC 0`) 锁定时整个 apply 跳过, 模式随之暂停

### 模式矩阵 (mode_*, 网页「模式」页)

解锁/平衡/步态/站立姿态这些开关不写死通道, 而是一张可配置表: 每行 = 一个通道 +
允许的档位区间。整张表是普通参数 (`modes` 组, 10 行), `!CFGW` 掉电保持。

| 模式 | 参数 | 默认 | 说明 |
|---|---|---|---|
| 解锁/上锁 | `mode_arm` | CH5 高 | **电平**语义: 停在区间内才解锁 (Betaflight 同款); 勾「单击触发」则改回按一下翻转 |
| 平衡模式 | `mode_bal` | CH8 高 | 同上 |
| 步态 波纹12 / 快三足4 | `mode_g0` / `mode_g4` | 未分配 | 出厂不占通道, 想用就在页面上勾 |
| 步态 三足6 / 三足8 / 波浪24 | `mode_g1` / `mode_g2` / `mode_g3` | CH6 低/中/高 | |
| 站姿 窄 / 正常 / 宽 | `mode_sn` / `mode_sp` / `mode_sw` | CH7 低/中/高 | |

- 打包 `ch<<3 | bits | click<<8` (参数范围 0~511): `ch` = 通道 id `0~19`, `31` =
  未分配; `bits` = 档位掩码 (低 1 / 中 2 / 高 4, 多选可叠加; `0` 也算未分配);
  `click` = bit8, 1 = 单击触发 / 0 = 按住生效 (默认)
- 解码时必须**先掩低 8 位**再取 `ch`: bit8 属于 click, 直接整体右移会渗进通道号
- 档位按原始值判定: `< 792` 低 / `> 1192` 高 / 其余中
- 同一个模式既能接遥控器二段开关 (只勾「高」), 也能接手柄按键 (按住 = 高)
- 多行同时命中时按表序, 后者胜 —— 两个步态行填同一个通道就是互相覆盖
- 页面上有六个实时徽标 (解锁/步态/平衡/站姿/高度开关/输入源), 数据来自固件每 2 秒
  的 `[RUN]` / `[IDLE]` 摘要尾缀 `Bal:%d St:%d Hi:%d`

**单击触发 (勾选框, 两协议同一个语义)**: 只在**进入**激活区间的沿动作一次 ——
解锁/平衡 = 翻转一次 (复刻更早的边沿语义), 步态/站姿 = 进档选一次 (锁存, 离开再进
才再触发)。手柄按键天生是边沿动作, 不勾就是按住生效; 遥控开关默认是电平动作,
勾上就变成拨一下切换。

- 多行目标 (步态/站姿) 里**电平行优先**: 只要有一行按住型激活, 单击行这一帧就完全
  不响应。默认 CH6/CH7 三段把量程铺满, 所以对它们勾单击是无效的 —— 想用单击先把
  对应通道上的电平行取消
- 沿状态在每帧末尾**无条件**整表刷新 (不经过下面的让位规则), 否则改完配置恢复求值
  的那一帧会拿旧值算出假沿

### 组合键 (combo_*, 同一页, 两协议通用)

手柄没有开关通道, 一次性动作改由按键表达 (遥控上按键即通道 CH5~CH16, 见下),
同样是可配置参数 (`modes` 组, 9 行):

| 动作 | 参数 | 默认 | 值 |
|---|---|---|:---:|
| 解锁/上锁 | `combo_arm` | START 单击 | 515 |
| 平衡模式开关 | `combo_bal` | SELECT 单击 | 512 |
| 步态 下一个 / 上一个 | `combo_gnext` / `combo_gprev` | ↑ / ↓ | 516 / 518 |
| 站姿 下一档 / 上一档 | `combo_snext` / `combo_sprev` | → / ← | 517 / 519 |
| 抬腿高度 ±5 | `combo_lup` / `combo_ldn` | × + ↑ / × + ↓ | 142 / 206 |
| 急停 | `combo_estop` | ○ 单击 | 525 |

- 打包 `btn_a | btn_b<<5 | hold<<10` (参数范围 0~2047): `btn` = 按键下标 `0~15`
  (位序见下表), `16` = 无; `hold` = bit10, 1 = 按住生效 / 0 = 单击触发 (默认)
  - `btn_b` = 无 → **单键**: 点 `btn_a` 触发一次 (上升沿)
  - `btn_b` ≠ 无 → **和弦**: 按住 `btn_a`, 再点 `btn_b` 触发一次
  - 按住生效时: 解锁/平衡在按住期间保持; 一次性动作 (切步态/站位、抬腿、急停)
    按下即触发, 继续按住每 400ms 重复一次 (计时用毫秒时间戳, 与 loop_ms 无关)
- 和弦优先: 和弦触发后两个键的沿都被消耗, 不会再触发同键的单键动作
  (所以 ×+↑ 抬腿不会顺带切成下一个步态)
- **按键来源按协议**: PS2 = 真按键 (按下 = 置位); CRSF = 通道 CH5~CH16 派生
  (`> 1192` 算按下, 与矩阵的高档同一阈值), 于是遥控器两个开关也能表达和弦
  - △ / ○ / × / □ 对应下标 12~15, 而 CRSF 只有 16 个通道 → 这四位在遥控上
    **永远不置位**, 默认的抬腿 (×+↑) 与急停 (○) 组合键在遥控上不可能误触发
  - 阈值取 >1192 而不是 >992: 中位抖动不会把开关抖成"按下"
- **让位规则 (两协议方向相反, 保证出厂配置两边行为都不变)**:
  - PS2 帧: 某目标**已配组合键** → 跳过该目标的矩阵行。否则默认表下按 SELECT
    会顺带命中矩阵行里的通道。把组合键设成「无」(16) 就把该目标交回矩阵
    (可以拿手柄某个键当解锁开关, 按住 = 解锁)
  - CRSF 帧: 某目标的矩阵行**已分配** → 跳过该目标的组合键。默认 CH5~CH8 都走
    矩阵, 组合键不抢; 把矩阵行设成「未分配」即把该目标交给组合键 (遥控的两个
    开关就能当解锁/平衡用)
  - 让位一取消, 组合键就按自己的按键下标落到遥控通道上 —— 默认 `combo_arm` 的主键
    是 START (下标 3) = **CH8**, 与默认平衡开关同通道。所以「把矩阵行设成未分配」
    这一步通常要连着把该组合键的主键也改到空闲通道 (否则那个开关会同时干两件事)
- 急停在行程计算**之后**执行, 不会被同一帧的摇杆映射覆盖

### PS2 手柄映射 (bit-bang SPI GP6~GP9)

| PS2 接收器引脚 | GPIO | 说明 |
|:---:|:---:|---|
| DAT (DI) | GP6 | 手柄→主机数据, 输入+内部上拉 |
| CMD (DO) | GP7 | 主机→手柄命令, 推挽输出 |
| SEL (ATT) | GP8 | 片选, 通讯期间拉低 |
| CLK | GP9 | 时钟, 空闲高 |

按键位序 (组合键参数里的下标就是它; 括号内是出厂默认动作):

| 下标 | 按键 | 下标 | 按键 |
|:---:|---|:---:|---|
| 0 | SELECT [平衡模式] | 8 | L2 |
| 1 | L3 | 9 | R2 |
| 2 | R3 | 10 | L1 |
| 3 | START [解锁/上锁] | 11 | R1 |
| 4 | D-Pad ↑ [步态下一个 / 抬腿 +] | 12 | △ |
| 5 | D-Pad → [站姿下一档] | 13 | ○ [急停] |
| 6 | D-Pad ↓ [步态上一个 / 抬腿 −] | 14 | × [和弦前缀] |
| 7 | D-Pad ← [站姿上一档] | 15 | □ |

**默认表下的操控** (一张表, 改完立即生效, 无需重烧):

| 操控 | 正常模式 | 姿态模式 (平衡) |
|---|---|---|
| 左摇杆 ←→ (LX) | 原地旋转 | 机身偏航 |
| 左摇杆 ↑↓ (LY) | 机身高度 (积分, 回中保持) | 机身高度 |
| 右摇杆 ←→ (RX) | 左右平移 | 机身横滚 |
| 右摇杆 ↑↓ (RY) | 前进/后退 | 机身俯仰 |
| START | 解锁/锁定 — 组合键是**边沿**, 按一下翻转 | 解锁/锁定 |
| SELECT | 平衡模式开关 (进入响一声) | 平衡模式开关 |
| × + D-Pad ↑↓ | 抬腿高度微调 | 抬腿高度微调 |
| ○ | 紧急停止 | 紧急停止 |
| □ / L3 / R3 / L2 / R2 / L1 / R1 / △ | 未分配 (可自行接线到模式矩阵或组合键) | 同左 |

> 「CRSF 等效」不再有硬绑定的通道: 上表里 START/SELECT 这些动作走的是组合键参数,
> 想换成别的键、或改成别的触发方式, 都在网页「模式」页改 —— 手柄侧取消该组合键的
> 「单击触发」就是"按住才解锁"; 遥控侧给矩阵行勾上「单击触发」就是"拨一下翻转"。
> 一套参数因此能同时适配两种控法: 矩阵行的勾选框管遥控器, 组合键的勾选框管手柄
> (出厂配置下正是一边走矩阵、一边走组合键, 互不干扰)。

## 鲁棒性保护 (watchdog-i2c-recovery)

### 硬件看门狗
- RP2040 硬件 Watchdog，超时 1500ms
- 主循环每迭代喂狗
- 任何死锁 (I2C 卡死 / ISR 风暴) 在 1.5s 内自动复位
- 调试器挂接时自动暂停 (pause_on_debug=1)

### I2C 总线恢复
- 连续 3 次 I2C 写入失败 → 自动执行总线恢复 (`pca9685_i2c_recover`)
- 恢复流程: 检测 SDA 是否被拉低 → 发送 9 个 SCL 脉冲释放 → STOP 条件 → 重新初始化 I2C
- 标准 I2C 规范 3.1.16 流程，耗时约 1-2ms
- 成功后连续失败计数归零，正常继续

### 启动阶段 I2C 卡死防护 ★2026-08

- 事件: 电压尖峰打坏 I2C 器件后总线被拉死 → 启动时 pca9685_init 阻塞式读写
  永久挂起, 症状 = 无提示音 + 无看门狗复位 + 无声死机 (开机日志停在
  "Boot OK. Servo power OFF — waiting for ARM switch.")
- 根因: `PCA9685_I2C_TIMEOUT_US` 宏早已定义 (5000µs) 但**从未接入任何 I2C 调用**
- 修复: 全部 I2C 阻塞调用改为 `_until` 变体 + 5ms 超时
  (hexapod_i2c_protocol.c 7 处 / bno055.c 5 处 / hexapod_hal_pico.c 3 处)
- 加固 (hexapod_pico.c):
  - 启动提示音提前到 robot_init 之前 — 有声=电源/蜂鸣器正常;
    间隔重复提示音 = 初始化反复挂起 (看门狗复位循环)
  - 看门狗提前到 robot_init 之前 (启动阶段 5s, 初始化完成后收紧 1.5s);
    初始化失败诊断循环内喂狗保持存活 (红灯闪 + USB 命令可用)
- 排障方法: 断电测 SDA/SCL 对地电阻 (≈0Ω = 器件把总线拉死);
  逐个断开 I2C 器件上电, 听到正常启动音即找到凶手

### PCB I2C 与电源保护设计 (事件 3 对策)

> 事件 3 复盘: 2S 尖峰 → AO4407A 击穿 + ADC 损坏 + 整条 I2C 总线器件全部失联。
> 旧板 I2C 裸连 (零限流/零钳位), 仅靠 Pico 内部 ~50kΩ 上拉。
> 尖峰可能的入侵路径: ① VBAT 直穿 PCA9685 输出级→逻辑级→I2C;
> ② 瞬态沿 PCB 走线耦合到 SDA/SCL; ③ 大电流回流引起地弹。
>
> ★ 2026-08-16 根因新推演 (用户猜想, 高度吻合): **PWM 引脚与相邻 VBAT 意外触碰**
> 是源头。旧板 PWM 输出零串联电阻 (成品模块均有), 触碰时灌入电流仅受芯片
> 内阻限制 → PCA9685 输出级 NMOS 击穿 → V+ 域 (7.4V) 穿通到 VCC 域 (3.3V)
> → SDA/SCL 带故障电平 → 沿裸连的 I2C 总线击穿另一颗 PCA9685、BNO055、
> Pico GP14/15 及邻近 GP26(ADC)。"2S 尖峰"可能即此短路的瞬态本身。
> IMU 后续发热 = 输入结构打穿后内部短路/闩锁持续拉电流 (不断电会持续恶化)。

#### 按性价比排序的保护清单

> ✅ = 已在新 PCB 落地; 其余为设计建议, 供下版/维修参考。

1. **PWM 输出串联电阻 (★事件根因对策, 投入产出比最高)**
   - 每路 PCA9685 LEDn 输出串 220Ω~470Ω (对照成品模块做法)
   - 触碰 VBAT/GND 时限流至几十 mA, 输出级扛得住, 芯片不死
   - 兼改善长舵机线反射振铃

2. **VBAT 与信号端子物理隔离**
   - 电池端子远离舵机信号排针, 布局分侧
   - 防呆/带护套连接器, 杜绝错插搭接

3. **源头钳位** ✅ 已在新 PCB 落地: 入口 SMBJ18A + 每颗 AO4407A 两端各 SMBJ12A
   - VBAT 电池入口: SMBJ18A 反并联 (击穿 20V, 钳位 ~29.2V) — 覆盖 4S 误接稳态
     (16.8V 不导通, 由固件过压检测拒绝开舵机供电兜底)
   - 每颗 AO4407A 源漏两端: SMBJ12A (击穿 13.3V, 钳位 ~19.9V) — 直接对策
     事件 3 的 Vds 击穿失效模式, 把 Vds 压在 30V 额定以下留足裕量
   - 配合关系: FET 导通时 Vds≈0, 跨 FET 的 12A 看不到轨上尖峰, 由入口 18A 兜底;
     FET 关断时 12A (13.3V) 先于 18A (20V) 动作
   - 舵机供电轨 (AO4407A 之后): 100µF 电解吸收尖峰能量
   - 注意: 4S 误接时 12A TVS 稳态导通 (16.8V>13.3V), PPTC 应动作 — 本板勿长期接 4S

4. **I2C 总线三级保护 (每线 <¥1)** ✅ BNO055 stub 已落地
   - SDA/SCL 各串联 100Ω, 串在 BNO055 分支 (stub) 上, 电阻靠近器件引脚
     (主总线保持完整走线; 注意 100Ω 隔离不了硬短路, 真正隔离需分支缓冲器, 见第 9 条)
   - 双向 TVS 钳位: PESD3V3 (单线) 或 SRV05-4 (4 线阵列)
   - 外置上拉 2.2k~4.7kΩ 到 3.3V (替代内部 ~50k — 兼改善 400kHz 信号边沿)

5. **器件侧解耦 (阻断输出级→逻辑级通道)** ✅ BNO055 VDD 限流已落地
   - 每颗 PCA9685: VCC (3.3V 逻辑) 100nF + 10µF; V+ (舵机电压) 100nF + 100µF + TVS
   - 上电时序: VCC 先于 V+ (AO4407A 供电门控天然满足), 防闩锁
   - BNO055 VDD 串电源限流电阻: 直接对策闩锁拖垮 3.3V 轨 — 即使 BNO055
     内部短路, 3.3V 轨只多几十 mA 负载, USB PHY 与其余器件不被波及

6. **ADC 输入保护**: 串联 1kΩ + 100nF RC + 3.3V 齐纳 (ADC 引脚已在 GP28)

7. **AO4407A 栅极**: 100Ω 串联电阻 + 可选 Vgs 齐纳钳位 (Vgs 极限 ±25V)
   ★ 跨 D-S 的 TVS 保护不到栅极 (FET 导通时 Vsg 随 VBAT 尖峰直接超限),
   事件 3 存疑分析后此项升级为建议落地 (G-S 齐纳, 如 15V)

8. **布局与地**: SDA/SCL 走线远离 VBAT/舵机 PWM 大电流走线;
   逻辑地与功率地单点汇接, 尖峰回流路径避开 I2C 走线下方
   ★ 事件 3 复盘升级为硬性要求: 旧板大铜箔与电池负极仅细线相连是主因之一
   (细线电阻=常驻地偏移致 ADC 读数异常; 细线电感=瞬态地弹打坏跨域信号)。
   电池负极到铜箔必须宽铜/多过孔星形汇接; 分压网络 R2 地参考 Kelvin 式
   直接回电池负极焊盘; 大电流回流不得与信号地共路

9. **进阶 (可选)**: I2C 隔离芯片 ADUM1250 (~¥10) — 舵机侧与 Pico 完全电气隔离,
   尖峰无法沿 I2C 到达 Pico, 一劳永逸

### 电路保护建议 (防止 ESD 击穿 + 5V 倒灌)
- **已发生事件 1** (2026-06): 手触碰板子 → ESD 静电击穿外部 QSPI Flash 芯片 → Pico 无法启动 (仅能进 BOOTSEL 大容量模式)
- **已发生事件 2** (2026-06): PCA9685 模块用 5V 供电 → I2C 上拉到 5V → 5V 倒灌入 GP2/GP3 → **烧毁 2 块 Pico**
  - 表现: Pico USB 可枚举但串口无法打开、GPIO 检测不到 I2C 设备、芯片严重发热
  - 已修复: I2C 复用引脚从 GP2/GP3 改为 **GP14/GP15** (PCB 靠近 PCA9685)，PCA9685 改为 **3.3V 供电**
- **已发生事件 3** (2026-08): 2S 供电侧意外电压尖峰 → 舵机供电开关 **2× AO4407A (P-MOS) 击穿** + **Pico ADC (GP26) 损坏**
  - 旧板已有防护: 大电流位置 (电机/舵机) 续流二极管 + 跨 AO4407A 的 TVS,
    但仍发生击穿 — 失效模式待查证 (2026-08-28 存疑, 见下)
  - 教训: 续流二极管只管感性负载反电动势, 无法钳位供电侧的瞬态尖峰
  - ★ 存疑 (2026-08-28): 旧板 FET 上已焊 TVS 却仍击穿, "漏掉 TVS" 解释不完整。
    候选机制:
    ① ~~焊的是 SMBJ18A~~ 已排除: 只购买过 SMBJ12A
    ② FET 导通时尖峰走栅极: Vsg=VBAT−0 超 ±25V 极限 → 栅氧击穿 (需要 >25V 地弹, 概率较低)
    ③ 持续过压 (12V 适配器 <13.3V 不触发 12A 管; 4S 使 12A 管稳态导通烧断)
    ④ 失效顺序或与推演相反: PWM 碰 VBAT → PCA9685 内部短路 → 7.4V 灌入
       3.3V 域/SDA/SCL, FET "击穿" 或为表象
    ⑤ ★ 接地结构 (用户确认旧板接地差: 大铜箔与电池负极仅细线相连) — 主嫌疑:
       - DC 层面: 回流电流 × 细线电阻 = 铜箔对电池负极常驻抬升 (数十~数百 mV)
         → 分压网络地参考偏移 → 电池 ADC "读数异常" 的直接解释
       - 瞬态层面: 细线电感 (nH 级) × 故障 di/dt = 地弹数伏 → 跨域信号被打坏:
         ADC 输入 (GP26 死) / SDA-SCL 共模 (BNO055 闩锁) / 栅极驱动参考
         (FET 误导通 → 线性区大电流 → 热击穿, 测起来同样是 D-S 短路)
       - 跨 D-S 的 TVS 只钳差模, 地弹时其两端相对电压不变 → 完全无效,
         "有 TVS 仍坏"不矛盾
    鉴别方法: 拆损坏 FET 测 G-S 是否完好 (G-S 短=栅氧, G-S 完好+D-S 短=热击穿/雪崩);
    查旧板大铜箔与电池负极的实际连接宽度
  - 关联: 此前 "ADC 分压读数异常" 很可能即此所致
  - 对策 (已在新 PCB 落地): 2S 电池入口 VBAT 对地并联 TVS 管
    (与既有 1N5822 防反接 + PPTC 配合); BNO055 增加 I2C stub 串联电阻 +
    VDD 电源限流电阻; ADC 输入端加 3.3V 齐纳钳位作二级保护;
    电池 ADC 改至 GP28 (顺带绕开损坏的 GP26 通道)
  - 后续恶化 (2026-08-16): IMU 明显发热 (损伤发展成内部短路/闩锁, 持续拉大电流) →
    拖垮共享 3.3V 轨 → Pico USB PHY 失效, **连 BOOTSEL 大容量模式都不枚举**;
    数字 GPIO 低压仍工作 (蜂鸣器响+红灯闪)。排障: 断电测 IMU VCC 对地电阻
    (≈0Ω=短路) / 上电测 3.3V 轨 (<3.0V=被拖垮, >3.6V=稳压器损坏) / 断开 IMU 再上电
    验证 USB 恢复。非固件原因: 固件在 IMU I2C 已死的情况下无法与之交互。
  - ★ 已结案 (2026-08-16): **拆下 IMU 后全线恢复** — I2C 正常、2× PCA9685 与
    Pico 均无损坏、USB 枚举恢复、PS2 手柄实测通过 (含控制映射/解锁/运行时切换)。
    结论: 发热 IMU 拖垮 3.3V 轨实锤; 更换 IMU 后此板可继续服役。
- **最小保护方案** (成本 < ¥5):
  - I2C SDA/SCL (GP14/GP15) 各串联 100Ω 限流电阻
  - 3.3V 对地并联 TVS 管 (SMAJ3.3A / PESD3V3)
  - **2S 电池入口 (VBAT) 对地并联 TVS 管** (如 SMBJ12A — 击穿 13.3V > 满充 8.4V, 钳位尖峰保护 MOSFET/ADC 分压网络)
  - PCA9685 用 3.3V 供电，不可 5V。若舵机需要 5V PWM，须加 I2C 电平转换模块 (TXS0104E / BSS138 MOSFET)
  - 板子装盒或贴绝缘胶带，裸露 GPIO 是 ESD 直接入口
- **强烈建议**:
  - 舵机独立供电 (2S LiPo → 7.4V → 舵机电源轨)，Pico 单独供电
  - PCA9685 端 SDA/SCL 各上拉 4.7kΩ 到 PCA9685 VCC (3.3V)，限制反灌电流
  - 3.3V 输出对地加 100μF 电解 + 0.1μF 陶瓷，抑制舵机 EMI
- **进阶**: SRV05-4 ESD 阵列 / I2C 光耦隔离 (ADUM1250) / 共模扼流圈

## 腿部防碰撞 ★仿真原型已验证 (2026-08-28)

- 问题: 大步幅或转弯+行走时相邻腿相撞/卡住, 不能设死步幅极限 (转弯行走需要大跨步)
- 仿真原型: tools/ik_gait_debug.py 已加入胫节段距检测 (与固件逐行对应的 FK) +
  两层防碰撞 (`--relax` 第二层局部松弛, `--clamp-z` 第一层步态级限幅);
  同步了固件步态表/腿几何/转向合成 (仿真的步态表与足端坐标此前与固件不符, 已修正)
- 分层方案:
  1. **步态级合向量限幅 (第一层, 治本)**: 转向合成后的每腿 travel 向量,
     按相邻同侧腿 (RF-RM/RM-RR/LF-LM/LM-LR) 的 x 与 z 走廊做相位感知
     扫描 (z_k(t)=init_k+t_k×p_k(t), p 为步态扫掠因子), 重叠时按比例
     压缩两腿向量 — **方向不变只缩放模长, 非死极限**: 常规场景不介入,
     极端组合才压缩 (实测最坏组合 scale 低至 0.2)
  2. **动态两腿间距松弛 (第二层, 治标)**: 胫节段距判据 + 横向虚拟斥力
     (带状态累积+阻尼, 摆动轨迹塑形为绕障弧线) + 抬升地板 (危险区抬高
     摆动腿) + 支撑腿小幅让路
- 实验结论 (最坏组合 = 前进+平移+转弯全满杆, 6 对胫节距统计):
  - 关键发现: 交叉常发生在**膝部高度** — 抬足端不动膝盖, 竖直方向无解;
    分开膝盖需 ~50mm 足端偏转, 超出局部松弛能力; 且胫节是对角线
    (膝点→足端), 足端 z 距约束不了对角线交叉 → 仅限 z 不够, x 也要限
  - 仅第二层: 三腿堆叠场景 0mm 救不回来 (最坏帧仍 0.2mm/26 帧<10mm)
  - 仅第一层: 所有场景 0 帧 <10mm; 一二层叠加: 全部步态全部组合
    min ≥ 20mm、0 帧 <10mm ✓
- 参数 (仿真实测): TIBIA_SAFE=30 ENGAGE=50, CORR=0.8mm/sub, BIAS 阻尼
  0.9/封顶 60mm, 抬升地板 35mm/斜坡 7mm, 限幅目标 45mm/下限 0.2
- 待办: 移植固件 — update_servos 拆"目标收集/限幅+松弛/IK"三段;
  hexapod_config.h 加上述参数; 固件用膝点距离代理胫节段距 (三角查表
  即可, 免段距解析解)

## 步态
- RIPPLE_12: 4抬腿+8支撑=12步, 占空比67% (`!G0`, `mode_g0` 出厂未分配)
- TRIPOD_6: 交替三角, 12步周期 (`!G1`, `mode_g1` 默认 CH6 低位)
- TRIPOD_8: 三角从容版, 16步周期 (`!G2`, `mode_g2` 默认 CH6 中位)
- WAVE_24: 极慢波浪, 每次仅1腿抬起 (`!G3`, `mode_g3` 默认 CH6 高位)
- TRIPOD_4: 快速三角, 1.5× 速度 (`!G4`, `mode_g4` 出厂未分配)
- 抬腿高度: 0→峰值→0 二次曲线 (无跳变)
- 地面支撑: 位移取反 (与抬腿方向相反, 已修复)
- 子步态插值: 1 gait step = 100 sub-units, 连续轨迹

### 步态选择 (出厂 = CH6 三段开关)

| 开关位 | 步态 | 参数 | 串口 |
|:---:|---|---|:---:|
| 低位 | TRIPOD_6 (三角 6 步) | `mode_g1` | `!G1` |
| 中位 | TRIPOD_8 (三角 8 步) | `mode_g2` | `!G2` |
| 高位 | WAVE_24 (波浪 24 步) | `mode_g3` | `!G3` |

### 站立姿态 (出厂 = CH7 三段开关)

| 开关位 | 姿态 | 缩放 | 参数 | 串口 |
|:---:|---|:---:|---|:---:|
| 低位 | 窄 (足端靠近机身) | 80% | `mode_sn` | `!M -1` |
| 中位 | 正常 | 100% | `mode_sp` | `!M 0` |
| 高位 | 宽 (足端外扩) | 120% | `mode_sw` | `!M 1` |

**过渡机制**:
- 静止时切换: 仅插值全局缩放值，不动腿（避免擦地）
- 行走中切换: 仅抬起的腿逐步向新位置挪，着地腿保持不动
- 单腿每周期限步长 2mm，防止长时间着地后抬起时骤跳
- 过渡速度 30×100/周期，极值切换约 1.3s 完成

### horn_offset 校准 (机械中心)

- 公式: `最终舵机角度 = IK 计算角度 + horn_offset`（invert 之后叠加）
- 含义: 摇臂装上舵机盘时齿轮错开一齿, 机械中心就偏了几度 —— horn_offset 记的就是
  「这一路的中位偏了多少」, 单位与 `!P`/`!HO` 同一套 (**0 = 中位 1500µs, ±900 = ±90°**)
- 位置: 运行期真源是每条腿的 `coxa/femur/tibia_horn_offset` (`leg_configs`), IK 每周期
  现读 —— `!HO` / 走查存下的值立即生效, 不必重启。默认值在 hexapod_config.h
- 网页: 「校准」页 ① 点格子选一路 ② 滑条/微调把这一路转到中立位 (`!P`) ③ 「设为中心」
  (`!HO`, 记下当前角度) ④ 全部调完按「保存到 Flash」。18 格的偏移显示来自 `!HOS`
- 串口: `!C` 走查 (`!+`/`!-` 转动, `!D` 存下当前角度, 从 0 = 中位开始),
  `!HOS` 读回全部, `!HO <id> <ang>` 单路写入
- 落盘: `!SAVE` / 网页「保存到 Flash」把 18 路偏移与 done 位写进 flash 校准记录;
  上电由 `store_apply_to_robot` 回放 (`hal_calib_import` 同时把值种回运行时真源,
  所以 boot 后网页再改一路也不会把其余 17 路抹掉)

## 非易失存储 (flash 校准 + 事件日志) ★2026-09

> 解决两个真实痛点: ① 校准值 (horn_offset / PWM 周期) 掉电即丢, 只能手抄回
> hexapod_config.h 重新烧录; ② 电池保护/校准等事件无历史记录, 事后无法复盘。
> 实现: `pico/Src/hexapod_store.c` + `pico/Inc/hexapod_store.h`

### 扇区布局 (2MB flash 末尾三块)

| 偏移 | 大小 | 用途 | 写入时机 |
|---|---|---|---|
| `0x1FD000` | 4KB | 运行时参数记录 (2316B, 按 10 页写入) | 仅 `!CFGW` |
| `0x1FE000` | 4KB | 校准记录 (56B, 整页写入) | 仅 `!SAVE` |
| `0x1FF000` | 4KB | 事件日志环形 (512 条 × 8B) | 页编程追加; 仅 `!LOGC` 擦除 |

固件 text ≈102KB (2026-09 实测), 末尾这三扇区之外全空; 三块物理独立, 互不影响
(参数记录作废不牵连校准记录, 日志写满不牵连前两者)。

```c
/* 校准记录 56B, CRC32 覆盖全部前置字段 */
typedef struct __attribute__((packed)) {
    uint32_t magic;              /* 0x43584548 "HEXC" */
    uint16_t version;            /* 1 — 版本不符即回退默认值 */
    uint16_t reserved;
    int16_t  horn_offsets[18];   /* 0.1°, ID = leg*3+joint */
    uint32_t done_mask;          /* bit i = 第 i 路已校准 */
    uint16_t pwm_period_us[2];   /* 板0/板1 (0x40/0x41) */
    uint32_t crc32;
} store_calib_record_t;

/* 日志条目 8B: 32 条/页; type=0xFF 表示已擦除(无效) */
typedef struct __attribute__((packed)) {
    uint8_t type; uint8_t flags; uint16_t data; uint32_t t_ms;
} store_log_entry_t;
```

事件类型: `BOOT` (data=看门狗复位原因) / `BATT_OV` / `BATT_CUTOFF` /
`BATT_WARN` / `BATT_RECOVER` / `CALIB_SAVED` (data=已校准路数) / `LOG_CLEARED`

### XIP 写安全 (单核 RP2040 的关键约束)

`flash_range_erase/program` 期间 XIP 停摆 → 窗口内执行到的**任何**代码
必须驻留 RAM, 否则取指挂死:

- 全部写路径用 `__no_inline_not_in_flash_func` 包装 (erase / program / erase+program)
- **`watchdog_update()` 是 flash 函数, 窗口内不可调用** → 直接写
  `watchdog_hw->load = 10000000` (5000ms×1000×2, RP2040-E1 errata 系数)
- CRC32 用位操作实现而**非查表**: 表在 `.rodata` (flash), 窗口内取指会挂死;
  56B ≈ 0.4ms, 相对数百 ms 的擦除可忽略
- 构建后用 `arm-none-eabi-nm` 确认 `store_flash_*` / `store_feed_*` 地址 ≥ `0x20000000`

### 写策略: 行走中不碰 flash

页编程关中断 1~3ms, 而 CRSF UART1 @420000 baud 的 32B FIFO 仅 762µs 即满
→ 行走中写 flash 丢帧约 4 倍, 且不足以触发 200ms 断链自动停走。

- `store_log_event()` 只入 16 条 RAM 环形缓冲 (满则丢最新, `s_dropped++`)
- 主循环每轮调 `store_flush_pending(safe)`, 每轮最多刷 1 条 (限制单次阻塞)
- `safe` = 未解锁 (`!robot_on`=false) 或校准模式中 (机器人静止);
  `!SAVE` 与启动时强制刷
- 断电最多丢当前会话 ≤16 条; BOOT/校准事件发生在安全上下文, 立即落盘

### 启动行为

- banner 末行是固件版本: `[VER] Hexapod <版本> (<git 短哈希>)`。版本串由
   `pico/cmake/gen_version.cmake` 在**构建时**生成头文件 (检出即带版本, 不必手工改
   版本号); 同一行也是 `!VER` 的输出。串口另一头的网页开始页靠这行显示"板上跑的
   是什么"。两个来源: 本地构建 = `git describe --always --dirty` (dirty 与短哈希都
   带出来); **发版 = 工作流把正在发的 tag 明着传进去** (`-DHEXAPOD_FW_GIT_OVERRIDE`)
   —— 2026-09-28 实测, v0.4.0 那次 CI 里 `fetch-depth: 0` 也没让 `git describe` 看见
   刚推的 v0.4.0 (老 tag 在), 编出来报的是 `v0.3.0-56-g9be97c7`, 所以这个串不靠 CI
   的 git 状态猜; tag 要打 annotated (`git tag -a`), 轻量 tag 本地构建 describe 不认
- 紧跟一行是硬件版本: `[HW] PCB v2`。它**不是从板子上读出来的** —— RP2040 没有能区分
   PCB 版本的东西 (unique ID 是每片芯片各自的, 不是板型), 所以它是
   `hexapod_config.h` 里的常量 `HEXAPOD_HW_VERSION`: 换板改这一处重编。`!VER` 与
   开机横幅共用同一个打印函数, 两处都出这两行; 网页开始页与调参页状态栏都显示它

1. banner 后 `store_init()`: 线性扫描定位环头 (首个 `type==0xFF`) → 写 `BOOT` 事件
   (此时看门狗尚未启用, 写安全)
2. `robot_init()` 后校验校准记录 (magic + version + CRC32): 通过 →
   `store_apply_to_robot()` 覆盖默认 horn_offset 与 PWM 周期, 打印
   `[STORE] Calibration loaded from flash (N/18 servos + periods)`;
   失败 (空 flash / 断电写坏 / 版本不符) → `[STORE] No valid calibration — using
   defaults`, 回退 `hexapod_config.h` 默认值
   - **只套用 `done_mask` 置位的舵机**: 记录里的偏移只对校准过的位有意义,
     没校准的位是导出时的原值 (没标过的路就是 0)。校准到一半就 `!SAVE`
     (只调了 3 路) 是正常用法, 无条件套用会把这 15 条腿的默认偏移冲成 0
     直接错位 —— `done_mask` 写进记录就是为了防这个。开机行的 `N/18` 就是
     实际吃进去的路数。
   - 回放同时把值种回 HAL 的运行时真源 (`hal_calib_import`): `!HO`/`!C` 与
     `!SAVE` 共用那一份, 少了这步开机后只标一个舵机再 `!SAVE` 会丢掉记录里
     其余 17 路。
3. `!SAVE` 写入后回读校验, 不符则重试一次; 仍败 → `[STORE] Save FAILED`

### 安全护栏

- `!SAVE` / `!LOGC` 在已解锁 (行走) 状态被拒绝, 提示先 `!S` 停走 —
  `!LOGC` 的整扇区擦除耗时数百 ms, 行走中执行必然丢帧
- 无校准数据 (`done_mask==0`) 时 `!SAVE` 拒绝 —— 刚开机没标过任何一路时
  真源是空的, 这一条挡住的正是"开机随手点保存"
- `!SAVE` **允许在校准模式内使用** — `!C` 调完直接落盘是自然工作流
  (校准模式机器人必然静止, 属安全上下文)
- 部分校准 (`0 < done_mask < 全置位`) 允许保存: 已调过的腿落盘, 没调过的
  载入时不套用 (见「启动行为」)。所以"只校准一条腿先试"不会毁掉其余腿
- 单记录设计: `!SAVE` 中途断电会同时损坏新旧值, 接受并文档化 (回退默认值)

## 预留外设 (板载预留接口的在线控制)

PCB 上除主功能外还留了直流电机 / 蜂鸣器 / 双 LED / 外部 UART / 外部 I2C+ADC /
PCA9685 空闲 PWM。这些口子目前**都还没接负载**, 但固件已能开关和设置, 入口是
串口命令与网页「外设」页 (后者每 2s 轮询 `!PERIPH` 刷新)。

| 器件 | 引脚 | 命令 | 说明 |
|---|---|---|---|
| 直流电机 ×2 | GP2/GP3 | `!MOTOR <1\|2> <0-1000>` | 占空比 ×0.1%; **无方向引脚** → 只有转速, 无正反转; 无参 = 双停 |
| 绿 / 红 LED | GP25 / GP12 | `!LED <g\|r> <0\|1>` | 手动设值, 会被主循环周期写覆盖 (见下「所有权」) |
| 蜂鸣器 | GP13 | `!BUZZ <freq 200-10000> <ms>` | **阻塞** (ms 夹到 ≤2000), 期间控制回路停摆 |
| 外部 UART0 | GP0 TX / GP1 RX | `!UART0T <text>` | 需 `uart0_en=1`; 发送不加换行; 收到的行以 `[U0]` 转 USB |
| 外部 I2C | GP26 SDA / GP27 SCL | `!I2C2` | 需 `ext_i2c_mode=1`; 只做扫描 (0x08~0x77), 不做读写 |
| 外部 ADC | GP26 ADC0 / GP27 ADC1 | `!ADC2` | 需 `ext_i2c_mode=2`; 16 次平均后报 mV |
| 空闲 PWM ×14 | PCA9685 | `!PWM <idx 0-13> <us>` | 值夹到 [0, 本板当前周期]; `!PWMQ` 查询, `!PWMOFF` 全归零 |
| 总状态 | — | `!PERIPH` | 7 行 `[PER]`: motors / leds / buzzer / uart0 / ext / pwm / pwmperiod |
| 端口总状态 | — | `!PORTS` | 7 行 `[PORTS]`: uart0 / input / motors / foot / ext / gpio / fixed |

**LED 所有权**: 主循环里绿灯每 2s 写一次心跳、红灯每 1s 写一次电池状态, 手动设的
值会被冲掉。`led_heartbeat` / `led_alarm` 两个参数就是这两个周期写的开关, 网页上
手动控灯要先关掉对应参数。`!LED` 在覆盖即将发生时打一行 WARN, 免得对着"设了没反应"猜。

**空闲 PWM 的 14 路编号** (与网页标签、`!PWM` 用法行一致):

| idx | 板 / 物理通道 |
|---|---|
| 0~6 | 左板 0x40 LED0~LED6 |
| 7~13 | 右板 0x41 LED9~LED15 |

编号与 18 路舵机占用的通道**不相交** (左板喂 LED7~15, 右板喂 LED0~8), 所以能和
舵机同批写入而互不干扰。`hal_servo_flush()` 每次都是整板 16 通道全写, 空闲通道
必须**合并进同一批** —— 单独写一次会在下一次 flush (~20ms 后) 被 `pulses[]` 里的 0 冲掉。

PWM 值只在 RAM 里, 断电即 0 (无持久化)。**去扭矩 / 急停 (`!S`、锁定、机器人 OFF)
会把 14 路一并归零**: `pca9685_free_all()` 本就是整板写零、硬件上已经归零, 固件里
那份 RAM 值跟着清是为了不让 `!PWMQ` 报着旧值而 dirty 已清、再也补发不出去 ——
"全部输出停止"这条语义对空闲通道同样成立。

**外部接口的配置在 2s 内才生效**: 参数改动不是命令式应用, 而是 `hal_periph_poll()`
每轮比对一次配置快照, 变了才 `uart_init` / `uart_deinit`、重挂引脚
(`ext_i2c_mode` 切 I2C↔ADC 同理)。所以 `!CFG uart0_en 1` 之后最多等 2s 才见到
`[PER] uart0 ON`。收行上限 80 字节, 超长丢整行; 非打印字符 (控制符/退格/中文)
丢弃 —— 半行和乱码都不该进网页。

**扩展 ADC 与电池共用单例**: 读扩展通道前后必须切回 `BATTERY_ADC_INPUT`, 否则
下一次电池读数会落在 GP26/27 上 (现象是电压突然变成几百 mV)。

`pwmperiod` 行给的是两块板的**周期** (µs), 是网页控制页滑条的回读源: 网页改周期
走 `!PER0/1`, 回读走这行 —— 不必进校准模式。

> ⚠️ `[PER]` 前缀同时也是 PCA9685 周期校准 (`!PER`) 的输出前缀, 所以网页侧按
> 节名白名单 (motors/leds/buzzer/uart0/ext/pwm/pwmperiod) 匹配; `!PERIPH` 与 `!PER`
> 只差三个字符且 `!PER<i>` 是合法命令, 固件靠完整字面量区分。
> `!PER0/1` 与 `!PERQ` 的回显行**不在**白名单里 (正文不同), 走日志面板。

## 端口页 (引脚归属)

网页「端口」页是 Betaflight 端口页的语义: 一行一组引脚, 选这一组「现在是干什么的」。
下拉写的是**参数** (改完即时生效, 保存后掉电保持), 状态列报的是**引脚此刻的实测
电平** (`!PORTS` 轮询, 每 2s) —— 参数与硬件对不上时这一页看得出来。
(`uart0_en` / `input_mode` / `ext_i2c_mode` 在「外设」「遥控」页也各有一份显示,
同一个参数、两处联动。)

| 参数 | 引脚 | 取值 |
|---|---|---|
| `uart0_en` / `uart0_baud` | GP0/GP1 | 0=关闭 1=UART; 波特率可选 |
| `input_mode` / `input_baud_serial` | GP4/GP5 | 输入源 (CRSF/PS2)+串口模式波特率 |
| `dc_motor_en` | GP2/GP3 | 0=释放成 GPIO 输入 1=电机 PWM |
| `foot_sw_en` | GP16~GP21 | 0=GPIO 输入 1=足端检测 |
| `ext_i2c_mode` | GP26/GP27 | 0=关闭 1=软件 I2C 2=ADC |
| `gp23_fn` / `gp24_fn` / `gp29_fn` | GP23/24/29 | 0=输入 1=输出 (输出初值低); 脚本身是 Pico 板载 (见 GPIO 表) |

- **收回去的引脚不会假装还能用**: `dc_motor_en=0` 时 `!MOTOR` 直接回
  `[PORTS] motors: disabled (dc_motor_en=0)` 并拒绝 —— `hal_dc_motor_set` 是静默
  返回的, 不拦的话 `[PER]` 会报出一个根本没发生的占空比。同理 `foot_sw_en=0` 时
  足端读 API 一律报未触地 (引脚已归普通 GPIO, 拿它当开关读只会把上拉当触地)。
- **GP23/24/29 的电平是即时命令, 不落盘**: `!GPO <23|24|29> <0|1>` 只在 `gpXX_fn=1`
  (输出) 时接受, 输入态回 `[PORTS] GPO Refuse: gp23 fn=0 (need 1=output)`;
  写完立刻回打 gpio 行 (网页不用等下一次轮询)。切回输入再切输出会回到低电平 ——
  "这一脚现在什么电平"本来就不是能存的状态。
- **板载三脚当输入能读出什么 (真机实测)**: `gpio` 节报的 `lv` 是引脚的数字电平。
  GP24 = USB 在不在 (插着实测 1); GP23 = 模块此刻的电源模式; GP29 是 VSYS 的
  200k/100k 分压 (VSYS/3, 5V 下 ≈1.7V) —— 落在 RP2040 的逻辑门限之下, 数字读
  **恒 0** (电池 8.3V 供电、USB 插着都实测 0), 所以端口页 GP29 那一格电平看不出
  电池在不在。真要看 VSYS 得读 ADC3, 固件目前不读 —— 电池电压走的是另一路
  GP28 分压 (47/377), 与这三脚无关。
- **`input_baud_serial` 在真机上不动遥控链路**: 真机恒 CRSF (`input_baud` 420000,
  `input_mode` 被强制成 CRSF), 这个参数只对 `INPUT_CONTROL_MODE==2` 的串口输入
  构建有意义; 端口页的 `input` 节报的是 `uart_init` 返回的**实际生效**波特率,
  不是参数值 —— 改了没生效这一页看得出来。
- ⚠️ `[PORTS]` 是独立前缀, 网页侧同样按节名白名单
  (uart0/input/motors/foot/ext/gpio/fixed) 匹配; `[PORTS] GPO Refuse…` 这类正文
  不在白名单里, 照常进日志面板。

## 调试工具
- USB CDC 串口命令 (CRSF 模式下也可用), 完整列表:

| 命令 | 功能 |
|---|---|
| `!C` | 交互式舵机校准 (走查从 0 = 中位开始, `!D` 导出的 offset 就是 `!HO` 的角度) |
| `!VER` | 打印固件版本 `[VER] Hexapod <版本> (<git 短哈希>)` + 硬件版本 `[HW] PCB v2` — 开机横幅同款两行 |
| `!V` | 切换调试等级 (0-3) |
| `!P<id> <ang>` | 单舵机角度控制 (0=中位, ±900=±90°; 网页校准页的滑条走这条) |
| `!HO <id> <ang>` | 把这一路当前角度记成机械中心 (horn_offset = ang, 写入 `leg_configs`, 立即生效; 行走中拒绝) |
| `!HOS` | 打印 18 路 horn_offset (`[HO] id=<n> off=<ang>`, 网页校准页轮询用) |
| `!W<id>` | 舵机扫摆测试 |
| `!Z` | 所有舵机回中位 (0 = 1500µs) |
| `!A` | 打印全部 18 路舵机角度 |
| `!O [0\|1]` | 舵机供电: 无参 = 切换 (兼容老用法), 有参 = 直接置位; 关电顺带清行程 |
| `!S` | 停止 (清行程, 不断电) |
| `!RC [0\|1]` | 遥控门: 锁定 / 放开遥控输入 (无参 = 锁); 6s 无心跳自动解锁 |
| `!F` / `!B` / `!L` / `!R` | 方向移动 |
| `!G<n>` | 步态切换 (0-4) |
| `!M<n>` | 站立姿态 (-1=窄, 0=正常, 1=宽, 空格可省略) |
| `!T` | 平衡模式开关 |
| `!U` / `!D` | 抬腿高度微调 |
| `!I2C` | I2C 总线检测 (PCA9685/BNO055/全扫描) |
| `!I2C q` | 同上但跳过 128 地址全扫描 (网页轮询用, 省掉最坏 640ms 控制循环阻塞) |
| `!IMU` | IMU 状态 (欧拉角/中断/校准等级 + 加速度/陀螺/磁力/温度原始值, 带单位标注) |
| `!IMUR` | 重置 BNO055 校准 (整芯片复位 + 重新初始化, 清空标定值; 行走中拒绝) |
| `!BATT` | 电池 ADC 诊断 (原始计数/引脚电压/换算电压/32 次采样离散度/三态判定), 独立于 `batt_check` |
| `!PER` | PCA9685 PWM 周期校准模式 |
| `!PER0/1 <us>` | 设置左/右板周期并实时生效 (同时按新周期写硬件刷新频率) |
| `!PERO 0/1` | horn_offset 偏移量开关 (默认 ON) |
| `!PERS` / `!PERQ` | 周期校准重设 / 退出并打印最终值 |
| `!PS2` | 打印 PS2 手柄原始状态 |
| `!PS2DBG` | PS2 调试观察模式开关 (每秒打印通道值, 机器人不响应输入) |
| `!MODE crsf\|ps2` | 输入源切换 (同步写 `input_mode` 参数, `!CFGW` 后掉电保持) |
| `!SAVE` | 校准参数存 flash (掉电保持; 行走中拒绝, 需先 `!S`) |
| `!LOG` | 打印 flash 事件日志 (BOOT/电池/校准) |
| `!LOGC` | 清空事件日志 (行走中拒绝) |
| `!CFG` / `!CFG <n> [v]` | 运行时参数: 列出 / 查询 / 设置 (见「运行时参数」) |
| `!CFGR [n]` | 参数恢复默认 (无参 = 全部) |
| `!CFGW` | 参数存 flash (行走中拒绝) |
| `!MOTOR <1\|2> <0-1000>` | 直流电机调速 (×0.1%); 无参 = 双停 (见「预留外设」) |
| `!LED <g\|r> <0\|1>` | 手动控灯 (需先关 `led_heartbeat` / `led_alarm`) |
| `!BUZZ <freq> <ms>` | 蜂鸣器发声 (阻塞 ≤2000ms) |
| `!UART0T <text>` | 外部 UART0 发一行 (需 `uart0_en=1`) |
| `!I2C2` | 外部软件 I2C 扫描 (需 `ext_i2c_mode=1`), 结果缓存 |
| `!ADC2` | 外部 ADC0/ADC1 读 mV (需 `ext_i2c_mode=2`) |
| `!PWM <idx 0-13> <us>` | 空闲 PWM 单路设值 (idx 编号见「预留外设」) |
| `!PWMQ` | 打印 14 路空闲 PWM 当前值 |
| `!PWMOFF` | 14 路空闲 PWM 全部归零 |
| `!PERIPH` | 外设总状态 7 行 (网页外设页轮询用) — **不是** `!PER` (周期校准) |
| `!PORTS` | 端口总状态 7 行 (引脚归属与实测电平, 网页端口页轮询用) |
| `!GPO <23\|24\|29> <0\|1>` | 写 GP23/24/29 电平 (需该脚 `gpXX_fn=1`; 输入态拒绝, 电平不落盘) |

> ⚠️ `!SAVE` 与 `!S` (停止) 仅靠长度区分 — 固件按 `buf[1..4]` 精确匹配 "SAVE",
> 故 `!S` 仍是停止、`!SAVE` 才是存盘。`!LOG` / `!LOGC` 同理 (LOGC 更长)。
> `!VER` / `!V` (调试等级) 也是前缀撞车 —— `!VER` 在命令 switch **之前**拦截。
> `!RC` / `!R` (右移) 同理: `!RC` 必须在 `ctrl_state` 空指针检查**之前**拦截,
> 否则没解锁时遥控门命令自己就会被 `if (!ctrl_state) return false` 挡掉。
> `!PORTS` / `!P<id> <ang>` 与 `!GPO` / `!G<步态>` 也是前缀撞车, 两个都拦在
> switch **之前**: `!PORTS` 落到 `case 'P'` 会被读成「舵机 0 转到角度 0」(真会动),
> `!GPO` 落到 `case 'G'` 则一声不吭。`!PERIPH`/`!PORTS` 与 `!PER<i>` 靠完整字面量区分。
- **tools/serial_console.py**: USB 串口交互控制台 (2026-08 重写为手动行编辑器)
  - 半行输入不被串口数据打断 (固件消息到达时自动恢复正在输入的内容)
  - ↑↓ 命令历史, 退格, Ctrl+C 清行, Ctrl+D 退出, 超长命令拒发 (47 字符,
    与固件 `SERIAL_CMD_BUF` 一致)
  - 串口数据实时显示 (select 双路监听, 无需回车才刷新)
  - `!M -1` 与 `!M-1` 均可 (固件 parse_int 跳过前导空格)
  - ★ 2026-08 自动连接: 持续扫描端口 (by-id 中的 Pico 优先 → ttyACM*),
    设备出现即连接; 拔掉/复位/重新上电后**不退出**, 自动重连
  - ★ 先启动脚本再给机器人上电 → 捕获完整开机日志 (解决"开机时间窗口极短
    无法观察"问题); 未连接时输入的命令自动排队, 连接成功后立即发送
  - ★ 2026-09 TCP/IP 桥接: 串口数据经 TCP 广播给多个客户端, 客户端命令反向下发
    (`--port` 默认 7100, `--host` 默认 127.0.0.1, `--no-tcp` 可禁用)
  - ★ 2026-09 设备状态上报: 设备连上 / 掉线 / 端口被占时向所有客户端补发一行
    `[TCP] dev on|off|busy <port>`; 新客户端接入时先发一行当前状态。网页服务据此
    区分「桥接通」与「机器人在线」—— 桥接活着但 Pico 没插, 网页必须显示未检测到
- **tools/tcp_monitor.py**: TCP 桥接客户端 — 打印机器人输出 + stdin 行透传
  (`python3 tools/tcp_monitor.py [--host H] [--port 7100]`); 可多实例同时连接
- **tools/fake_robot.py**: 无硬件测试用假机器人 (配 socat pty 对), 附
  `!BURST <n>` 测试钩子
- `tools/test_bridge.py`: TCP 桥接端到端回归测试 (socat pty 模拟串口, 21 项断言 —
  双向转发 / 多客户端广播 / 慢客户端断开 / 串口重连恢复)

### ⚠️ 手工测串口输出时的三个陷阱 (会得出完全错误的结论)

1. **必须置 DTR**: `pico_stdio_usb` 见 DTR 才认主机在位, 否则**静默丢弃**输出。
   pyserial 默认不置位 —— 要写 `s.dtr = True`。不置位时现象是"命令没反应"
   或只收到后半段, 极易误判成固件 bug。实测同一命令: 不置 DTR = 30 秒无输出,
   置 DTR = 20ms 完整回显。
2. **确认没有第二个读者**: 两个进程同时开同一 `/dev/ttyACM0` 会互相偷字节,
   现象是"每次输出都稳定缺开头几行"。测前先 `fuser -v /dev/ttyACM0` 查干净
   (残留的 serial_console.py / server.py 是最常见来源), 测后确认释放。
3. **走网页链路时, 有些回显不进 raw 日志**: webconfig server 把解析成下列遥测帧
   的行从日志流里摘掉, 只在自己的帧里发 (要查 `GET /state`) —— `params` (参数回显
   `[P] name=value`)、`per` (`[PER] motors|leds|buzzer|uart0|ext|pwm|pwmperiod: …`,
   即 !PERIPH 与 !MOTOR/!LED/!PWM 的回显)、`ch`、`rc`、`run`、`ho` (`[HO] id=…
   off=…`)、`ports` (`[PORTS] …`)。现象是"命令发了、日志面板里什么都没有", 看着
   像命令没到或固件没回, 其实是回显在帧里。别的解析结果 (`[VER]`、电池、舵机快照、
   I2C 段) 照进 raw, 两处都看得到。
   ⚠️ 而且 raw 里的回显可能迟到好几秒 (固件正在打周期块时命令要排队) —— 别急着
   下"没反应"的结论: 实测同一条 `!VER` 的输出晚了 3 秒才出现在日志里。

### TCP 桥接的数据流与线程安全 ★2026-09

```
串口 fd ──读──> 主线程 ──bridge_publish()──> tcp_tx 队列 ──自唤醒管道──> TCP 线程 ──> 各客户端
客户端  ──> TCP 线程 ──> tcp_rx 队列 ──自唤醒管道──> 主线程 ──send_line()──> 串口 fd
```

- ★ **串口 fd 只由主线程读写**; TCP 线程只碰套接字; 两者仅经线程安全队列通信
- **两个方向各一根非阻塞自唤醒管道** —— TCP 线程的 select 空闲时要睡满 0.5s 超时,
  没人叫醒它就得等超时才动:
  - `_wake_r/_wake_w`: TCP 线程收到命令 → 立即唤醒主 select (否则命令等超时才被处理)
  - `_tx_wake_r/_tx_wake_w`: 主线程入队遥测 → TCP 线程立即转发给客户端。缺这根时
    空闲链路上的遥测与命令应答被按 500ms 一批押后 (端到端往返中位实测 502ms;
    补上后 20ms, 真机 7ms)
- `_clients_lock` 是**非递归**锁 → 发送与断开必须在锁外做:
  持锁 `send()` 会挡住主线程的 `bridge_publish()`; 持锁调 `_drop_client()`
  会自死锁 (它要重入取同一把锁)
- 单客户端积压 > 64KB (应用层队列) 判定为慢消费者并断开; 其余客户端不受影响
- 客户端命令复用 `send_line()` 语义 (同一套 15 字符截断/`!P` 前缀/排队);
  串口断连期间的命令存入 `state["pending"]` (单值, 只保留最新一条, 更早的直接丢弃), 重连后刷出
- **headless 运行**: stdin 非终端时自动跳过 termios 原始模式并完全不监听键盘
  (否则 stdin 恒可读会把主循环拖成忙等), 控制通道只剩 TCP —
  可在 N100 上做后台服务, 从另一台机器用 `tcp_monitor.py` 远程操作
- tools/ik_gait_debug.py: Python 仿真可视化
- **tools/webconfig/**: 网页配置台 (见下节「网页 Configurator」)

## 网页 Configurator (2026-09)

目标: Betaflight Configurator 式的网页端 —— 实时查看 + 在线改参数。
现提供: **开始页 (硬件在线检测 / 固件版本 / 烧录) → 点「连接」→ 调试页**、
只读仪表盘 + 命令输入、运行时参数在线改/存 (含通道映射与外设)、
通道实时显示、模式页 (矩阵 + 组合键 + 实时状态)、主动控制页 (舵机供电/行走/
遥控门/PWM 周期)、预留外设控制页。
两种开法: **② 直连** (Web Serial, 零安装 —— 板子插在开网页的这台电脑上, 见下文
「直连 (Web Serial)」) 与 **① 本地服务** (板子插在别人机器上 / 要烧固件);
后续见下节「路线图」。

### 架构 (两条数据路)

```
① 本地服务 —— 板子插在跑服务的那台机器上 (N100), 或要烧固件:
Pico ──USB CDC──> serial_console.py ──TCP:7100──> webconfig/server.py ──SSE──> 浏览器
                  (串口守护: 自动重连/广播)              <──POST──┘

② 直连 (Web Serial) —— 板子插在开网页的这台电脑上, 零安装:
Pico ──USB CDC──> 浏览器 ── 页面内解析 ──> 同一套渲染层
```

**页面只有一份**, 两条路共用 `handleFrame` 之后的全部渲染/参数/校准逻辑;
差别的只是帧从哪来、命令往哪去 (`MODE ∈ {server, direct, none}`, 启动时探测:
`?mode=` 强制 > `/state` 能取到 JSON 当 ① > 有 `navigator.serial` 当 ② >
都没有则提示换浏览器; `file://` 不特判 —— 那正是"双击本地 html"这条路, 相对路径的
`/state` 取不到就落到 ②)。① 里固件输出在服务端解析成帧,
② 里在页面内解析 —— **两份解析器由 `test_webconfig.py [6]` 逐帧差分钉住**。

- **① 为什么必须服务端桥接**: Web Serial 只能访问**浏览器所在机器**的 USB, 而
  Pico 插在 N100 上, 浏览器够不着那侧的 USB。② 正是给"板子插在自己手边这台
  电脑"准备的 —— 那种情况下浏览器自己就能当串口主, 不必装 Python、跑服务、
  配端口转发; 烧固件与多浏览器共享连接态仍只在 ① 有。
- **复用 serial_console.py 而非另写串口层**: 端口扫描/断线重连/多客户端广播/
  慢客户端剔除/命令排队都已实现且有回归测试 (test_bridge.py), 重写只会多一份
  要维护的 bug。代价是轮询命令会同时出现在串口终端里 (共享总线)。
- **SSE 而非 WebSocket**: 标准库即可实现 (WebSocket 需手写握手+分帧, 否则引入
  pip 依赖); 遥测是下行高频、命令是上行低频, SSE(下行, 浏览器自带断线重连)
  + POST(上行) 已足够。

### 文件与用法

- `tools/webconfig/server.py` — 桥接客户端 + SSE 广播 + 静态服务 + 轮询调度
- `tools/webconfig/flasher.py` — 设备检测 (扫 /sys) + picotool 烧录; 只此一处碰 USB
- `tools/webconfig/index.html` — 单页应用 (零依赖, 无构建步骤; 服务模式与直连模式共用)
- `tools/webconfig/test_webconfig.py` — 457 项回归 (解析器/烧录单测 + 固件契约 + socat 无硬件端到端, 含桥接转发时延、页面脚本执行与合成帧探针、直连解析器与 server 的逐帧差分、正则同源检查; 无 headless 浏览器时页面那几项自动跳过)
- `.github/workflows/release.yml` — 打 annotated tag (`git tag -a v0.4.0 -m ...`) 时编固件发 Release:
  附件 = uf2 + index.html + 硬件文件, 说明 = `.github/release-body.md` (面向使用者, 发版改它)
  后面接一段提交清单 —— GitHub 的自动清单对没有 PR 的提交只有一行 compare 链接 (实测),
  逐条清单由工作流自己 `git log 上一版..本 tag` 接上 (上一版取自 `git tag -l`, 不靠
  `git describe`: 它在 CI 里认不出刚推的 tag, 见下面「启动行为」); 固件版本串由工作流指定为 tag 名 (`-DHEXAPOD_FW_GIT_OVERRIDE`,
  理由见上面「启动行为」)。打 tag 前先把 `pico/CMakeLists.txt` 的
  `pico_set_program_version` 改成同一个号 (picotool 元数据, 不吃 tag)
- `.github/workflows/pages.yml` — 把 index.html 发布到 GitHub Pages (直连模式的托管)。
  **首次要在仓库里手动开一次**: Settings → Pages → Source 选 "GitHub Actions"。
  工作流自己建不了站点 —— `configure-pages` 的 `enablement: true` 实测被
  `Resource not accessible by integration` 挡下 (建站要的权限比 GITHUB_TOKEN
  能拿到的多, 2026-09-28 实测), 站点建好之后才轮到它发布
- `tools/webconfig/run.py` / `run.sh` — 本地服务启停 (start/stop/restart/status/logs)

```bash
# ② 直连: 板子插在本机时首选 —— 浏览器开 Pages 网址点「连接」即可, 无需下面的服务
# ① 本地服务:
python3 tools/serial_console.py       # 终端 1: 串口守护 (headless 运行即可)
python3 tools/webconfig/server.py     # 终端 2: 默认 127.0.0.1:8080
# 浏览器打开 http://127.0.0.1:8080 (浏览器在别的机器时用 VSCode 端口转发)
```

左栏 13 个标签页 (Betaflight 式分页) —— 参数按功能拆页, 不再是单页长表单:

| 页 | 内容 |
| --- | --- |
| 状态 | 电池电压 + 五张 IMU 曲线 (姿态 / 加速度 / 陀螺仪 / 磁力计 / 温度) / IMU 姿态 / I2C 设备表 / 18 路舵机角度 |
| 步态 | motion 组 10 项: 步长 / 抬腿高度 / 步态周期 / 高度积分开关 |
| 姿态 | stance 组 5 项: 窄-正常-宽三档缩放 / 过渡速度 |
| 几何 | geo 组 21 项: 腿节长度 (coxa/femur/tibia) / 初始站高 / 股-胫舵机零位 / 基节安装角 / 机身与足端偏移 (后-中-前三组)。**改完重启生效** —— 这些量在上电时用来构造六条腿的 leg_configs, 运行中会被平衡旋转与站姿缩放改写, 无法热重建 |
| 遥控 | tune + dir + chan 三组共 13 项: 死区指数 / 四个方向取反 / 统一通道映射。附输入源切换按钮 + 实时通道面板 (5Hz, 按协议原值显示) |
| 模式 | modes 组 19 项 (自定义控件): 10 行模式矩阵 (通道 + 低/中/高档位 + 单击触发) / 9 行组合键 (按钮 A/B 下拉 + 单击触发, 两协议通用) / 六个实时徽标 (解锁·步态·平衡·站姿·高度开关·输入源) |
| 电源 | batt 组 8 项: 保护总开关 / 阈值 / 分压比 / 监测间隔 |
| 平衡 | imu 组 4 项: 补偿开关 / 增益 / 两轴符号 |
| 控制 | sys 组 1 项: 控制循环周期 `loop_ms`。附主动控制卡: 舵机供电开/关 (`!O 1`/`!O 0`) / 行走与转向 (`!F`/`!B`/`!L`/`!R`/`!Q`/`!E`/`!S`) / 步态 (`!G0-4`) / 抬腿高度 (`!U`/`!D`) / 两块板各一条 PWM 周期滑条; 附固件回报的行程与遥控门徽标 (只读) |
| 校准 | 三张卡: 舵机 (**逐舵机中心面板**: 选中格子 → 滑条转到中立位 → 「设为中心」走 `!HO`, 另附走查 `!C` / 保存 `!SAVE` / 总线扫描 `!I2C` + 18 路角度与各自偏移 + I2C 摘要) · 电压标定 (固件读数/引脚电压/当前分压比 + 万用表实测值输入 → 算 `batt_ratio_milli` 并下发) · IMU 校准 (在线/Roll-Pitch/四级校准等级 + `!IMUR` 重置) |
| 外设 | per 组 5 项: LED 心跳/报警所有权 / 外部 UART 使能+波特率 / 外部 I2C-ADC 二选一。附 6 张控制卡: 电机 / LED / 蜂鸣 / 外部 UART / 外部 I2C+ADC / 14 路空闲 PWM |
| 端口 | port 组 6 项 (自定义控件) + 引脚实测电平 (`!PORTS` 轮询)。每行一组引脚选用途: UART0 GP0/1 · 输入 UART1 GP4/5 · 电机 GP2/3 · 足端 GP16-21 · 外部 GP26/27 改功能下拉即写参数; GP23/24/29 切输入/输出并用 `!GPO` 给电平 (这三脚是 Pico 板载, 见 GPIO 表); 固定脚 (I2C1/舵机电源/LED/BOOT/电池 ADC) 只读。详见「端口页 (引脚归属)」 |
| 日志 | 串口日志(实时) + 命令输入框(带 ↑↓ 历史) + 常用命令快捷键 |

- **六张曲线 (电池 + 五张 IMU) 共用一套历史**: 只留最近 1 分钟 (`CH_WINDOW_MS`),
  横轴按**真时间戳**铺开 —— 不是"最近 N 个点", 漏一帧或标签页被浏览器压成分钟级
  定时器时, 按点数铺会把那段静默挤掉。推点过一道时间闸门 (`CH_GATE_MS` = 250ms):
  合并快照会把同一批读数随每一帧重发 (浅合并, 见「解析在服务端」), 一个轮询周期里
  同一条读数会到好几帧, 不挡的话曲线以数倍速灌重复点。闸门按**时间**挡而不是按
  **值**挡 —— 静止时值不变也照样每秒长一个点, 曲线不会看着像停了。
  **代价**: 把轮询调得比 250ms 还快时, 快出来的点会被闸掉 (默认 IMU 0.2s 就快于它,
  所以曲线约 4Hz 封顶; 电池 2s 远大于它)。数据源是诊断帧 (`!IMU` 5Hz / 2s `!BATT`),
  真正的波形等路线图里的 `!TEL <hz>`。掉线 (`available: NO`) 时五条序列一起清空,
  与电池 `ABSENT` 清线同一个道理 —— 免得留下一条不再更新的幽灵曲线。
- **`!IMU` 轮询 5Hz (0.2s)**: 直连态 (页面 `iv.imu`) 与 server 态 (`--imu-interval`
  默认) 同值, 有静态检查钉住。它一次回十来行, 一次响应里**有解析器**的数据行由 raw
  白名单挡在日志面板外 (与 `[CH]` 同理)。
- **IMU 状态块整块折叠**: `=== IMU Status ===` 到页脚 `===================` 之间的行
  不进日志面板 —— 中间的杂项行 (表头/`INT_STA=`/`INT cfg readback:`/`SW rev:`/页脚)
  没有解析器, 5Hz 下是 25 行/秒, 600 行面板二十几秒就冲干净。折叠**只挡日志面板,
  照常解析**: 数据行要喂曲线 (`folded` 只进 raw 那条判断, 测试直接钉这个挂载点)。
  压噪不藏故障 —— 块内的 `fail:` 行 (连续失败计数) 与块外的 `[IMU]` 警告行都放行。
  边界字符串与固件打印一字不差、两边常量同值, 都有检查钉住 (差一个字符折叠静默失效);
  页脚半路丢了时按 `IMU_BLOCK_MAX` 兜底出块, 不把面板堵死。
- **I2C 检测块整块折叠**: 网页每 3s 轮询一次 `!I2C q`, 表头 `=== I2C Bus Check` 到
  页脚 `Bus idle:` 之间那几行 (7 行; 手动全扫描时 ~137 行) 都是喂卡片的诊断值, 卡片
  上都有 —— 同样只挡日志面板, 照常解析 (卡片吃的是同一批 `i2c` 帧)。压噪不藏故障:
  块内 `NOT FOUND` / `present but` (设备掉线、CHIP_ID 不对) 照常进日志。表头/页脚是
  **前缀**匹配 (后面还带引脚名 `(SDA=GP14…) quick` 与两路电平读数), 与 IMU 块的
  整行相等不同; 常量同值、前缀写法、放行条件都有检查钉住。
- **重绘只有一个入口**: `drawAllCharts()`, 四个调用点 —— 切到状态页、进调试页、
  窗口 resize、掉线清空序列之后。画布在隐藏页里 `clientWidth=0`, 绘制函数会早退,
  所以**进页时必须重画一次**; 少一个调用点就表现为"进了状态页图是空的"。

- **页面归属由固件的 `grp=` 决定**: 前端只有一张 `PAGES` 表 (index.html) 把组映射到页,
  参数属于哪页完全跟着固件参数表的 group 字段走。新增参数忘了配页面时, 契约测试
  会报「无归属分组」。
- **每页的「恢复默认」只重置本页的组**: 固件没有 `!CFGR <组>` 语法, 由 server.py
  的 `_reset_group()` 按参数快照展开成多条 `!CFGR <name>`。对比日志页命令框的
  裸 `!CFGR` = 全部恢复。
- **参数行尾的「?」**: 名字看不出用处的参数 (loop_ms / stance_speed / ch_deadband …)
  在名字后带一个「?」, 悬停出解释气泡。解释文字只是一张前端表 (`HELP` in index.html),
  不在固件里; 契约测试校验每个键都是真参数 —— 键名拼错的唯一表现是那个「?」不出现,
  属于静默失效, 所以由测试钉住。
- **「保存到 Flash」各页等价**: `!CFGW` 本就是整份参数写 flash, 没有分组语义。
  无未保存改动时置灰 (语义与基线见下「前端行为」)。

### 开始页 → 连接 → 调试页 (Betaflight 语义)

打开网页先是**开始页**: 只有硬件状态 (网页服务 / 串口桥接 / 机器人设备) 与一张
固件卡 (板上版本 / USB 检测 / 可烧录 .uf2), 外加一小块桥接日志 (开机横幅落在
这里)。参数滑条与命令框全在调试页的 `#app` 里, 连接前它们连 DOM 都不显示 ——
这就是"没插机器人时改不了任何参数"的实现方式。

- **连接态在服务端, 不在浏览器**: 服务端记住"当前连着", 轮询 (`!BATT`/`!IMU`/
  `!A`/`!I2C q`/`!PERIPH`) 只在连接态下跑, `POST /connect` 顺带下发一次 `!CFG`
  拉参数表 (调试页首屏要用)。刷新页面不改变连接态。
- **为什么连接前绝不轮询**: serial_console 在没有设备时会把 TCP 命令**排队**,
  设备回来时重放 —— 没连接还轮询, 插上机器人的那一刻就是积压命令的洪水。
- **设备状态只有桥接知道**: serial_console 不在时设备行显"未知"而不是"未检测到"
  —— 此时板子可能还插着, 只是问不到 (桥接重启后会自己补发当前状态)。
- **进**: 「连接」按钮只在桥接与设备**都在线**时可点 (否则禁用, 并在下面写明是
  哪一环缺: 桥接没跑 / 端口被别的程序占着 (附 `fuser -v` 提示) / 没检测到机器人)。
  点它 → `POST /connect` → 服务端再确认一次 → 进调试页。
- **出**: 调试页顶栏「断开连接」走 `POST /disconnect`。拔 USB、桥接断开、或最后
  一个浏览器页面关掉, 服务端都会作废连接态并广播 `conn`, 所有开着的页面一起跳回
  开始页 (并写明原因: 设备已断开 / 桥接已断开 / 已断开连接)。
- **多浏览器**: 连接态是全局的 —— 一个机器人一条串口, 没有"每个浏览器各连各的"
  语义。任一标签页点连接, 其他标签页跟着进调试页; 点断开则一起回开始页;
  最后一个标签页离开时连接态自动复位 (否则"没人看却在轮询")。
- **拔线后再插回不自动重连**: 设备重新在线只让「连接」按钮可点, 得用户再点一次。
  自动重连会让"插上就发命令"发生在用户没看屏幕的时候。
- 固件与硬件版本的显示不依赖连接: 设备一上线服务端就发一次 `!VER`, 开始页的两行
  版本 (`板上运行` / `硬件版本`) 直接显示; 进了调试页还有一份在**底部状态栏**的
  行/秒旁边 (`固件 … · 硬件 …`, 原文照抄不裁剪 —— 裁剪要脆弱正则, 零收益)。
  这两行**不能放在开始页的固件卡里**: 直连态整卡隐藏, 放里面就跟着一起看不见 ——
  卡里只剩 USB 检测与烧录, 版本行在通用状态区 (通用状态区的行直连态照常显示)。

**遥控门 (调试期间遥控器能不能控制机器人)**: 连接按钮上方一个开关「调试时允许
遥控器控制」, 不勾 (默认) 就是连接时锁定 —— 机器人在调试页期间只听 USB 命令。
勾选状态随 `POST /connect` 的 body (`{"radio": bool}`) 一起发给服务端。

- **锁定 = 固件里的 `!RC 0`**, 由服务端维持: 连接时发一次, 之后每 ~2s 心跳重发
  (`--rc-interval`, 默认 2.0, 0 = 关; `--no-poll` 时一并清零)。
- **固件 6s 无心跳自动解锁** (`RC_LOCK_TIMEOUT_MS`): 网页/服务端崩了不会把机器人
  永久锁死, 遥控器自己拿回控制权 —— 这是 fail-safe 的方向。
- **释放**: 断开连接、拔 USB、桥接断开、最后一个页面关掉, 四条路径都发 `!RC 1`;
  桥接重连时若浏览器仍连着则立即重锁 (固件可能已超时自解锁)。
- **只在设备在线时发**: 桥接缺席时命令会排队, 重连时重放 —— 打到刚上电的机器人
  上就是意外动作。锁定期间**不受轮询暂停影响** (暂停是"别再问数据", 心跳不是问数据)。
- 锁定期 `[CH]` 通道遥测照常推送 (遥控页仍实时显示), 只是不应用到机器人;
  调试页的 `!F`/`!B`/… 照常生效 —— 这正是锁定要的效果。

### 直连 (Web Serial, ★2026-09)

板子插在**开网页的这台电脑**上时走这条: Chrome/Edge/Opera 打开
<https://gitcfyang.github.io/hexapod_robot/> (GitHub Pages 托管, 由
`.github/workflows/pages.yml` 在 index.html 变更时自动发布, 有约 10 分钟缓存),
或**本地那份 `index.html` 双击打开**, 或任何 HTTPS / localhost 上的同一份页面
→ 「连接」→ 浏览器弹串口选择器 → 选中 Pico → 进调试页。备选的开法: **本地那份
`index.html` 双击打开** (file://, 不用等发布也不联网), 或任何 HTTPS / localhost 上的
同一份页面 —— 三条路页面完全一样, 只是来源不同。Safari 用不了 (没有 Web Serial);
Firefox 需 151+。URL 加 `?mode=server|direct|none` 可强制某条路 (本地开发对着静态服务调、
单测探针钉模式都用它)。

- **页面自己当串口主**: `navigator.serial.requestPort()` → `open(115200)` 之后
  reader/writer 全在页面里; 命令直接写串口, 帧由页面内解析器产出 —— 没有服务端、
  没有 TCP 桥接。串口选择器要**用户手势**: 「连接」的处理函数里 `requestPort`
  必须是第一个同步调用 (中间先 await 一次网络往返, 用户激活就作废, 弹窗根本不出现),
  这是 `enterDebug` 直连分支里那句"不能先 await 任何东西"的原因。
- **开端口先排空**: 端口打开前固件已经在推 `[CH]` 等行, 直接解析等于把打开前的
  状态当成现状。排空 = 连续 0.2s 静默 **或** 总共 1.5s 为止 —— 两个出口缺一不可:
  5Hz 的 `[CH]` 每 200ms 就来一行, 只按静默判会永远静不下来 (与
  serial_console.py 的排空同款)。
- **轮询与遥控门心跳都在页面里**: 与 ① 同一张表 (batt 2s / imu 1s / 舵机
  `!A`+`!HOS` 2s / `!I2C q` 3s / `!PERIPH` 2s / `!PORTS` 2s / `!RC 0` 心跳 2s,
  0.1s 一拍), 暂停轮询不停心跳 (同 ① 的语义)。标签页进后台时浏览器把定时器压成
  分钟级 → 心跳停 → 固件 6s 超时自解锁 (fail-safe 方向, 接受); 回前台补发一次
  心跳并重拉 `!CFG` 同步 (页面可能在后台漏掉了参数变更)。
- **直连没有的东西**: 烧固件 (Web Serial 烧不了 uf2 —— 开始页的固件卡、桥接日志区
  与烧录入口在直连态整块隐藏, 顶部横幅也换成"断开的是串口"的说法)、跨浏览器共享
  连接态 (Web Serial 端口排他, 一个标签页独占一个串口, 没有"多浏览器各连各的"),
  桥接/设备在线状态 (直连态显示的就是串口自身状态)。
- **直连态的版本只能靠记**: 版本要连上串口才知道 (握手发一次 `!VER`), 而连接后直接
  进调试页 —— 服务端那种"设备一上线就显示"在直连态不存在。读到一次就写进
  localStorage (`hexapod_ver`/`hexapod_hw`), 再打开开始页先用缓存填上, 帧来了覆盖
  (帧为准, 缓存只兜底)。清过浏览器数据/换浏览器的**首次**访问显示「—」: 没有用户
  手势连不上串口, 此时物理上读不到, 不是坏了。
- **`file://` 也是合法入口** (双击本地 html 那条): Chrome 把 `file://` 当安全上下文,
  `navigator.serial` 实测可用 (无头 Chrome 154), 页面探不到 `/state` 便落到直连 ——
  所以 `file` scheme 不特判。回归由 `test_webconfig.py` 两条钉住: 静态查
  `location.protocol` 不再出现在页面里 + 真开一次无头浏览器看它探成 `direct`。
  未验的一环: **`file://` origin 弹不弹串口选择器、权限给不给**(无头没有串口后端,
  `getPorts()` 在那儿根本不落定, 这一层测不了) —— 只能人工点一次, 见下面的验收清单。
- **待人工验收** (无头浏览器测不了真实串口时序, 是发布门槛):
  `python3 -m http.server 8000` 静态托管 + Chrome 直连实板走一遍 —— 连接/端口
  选择器 → 参数页滑条改值 → `!CFGW` → 端口页下拉 → 断开后遥控器恢复 → 拔 USB
  掉线回开始页; 再加一档: **同一个文件双击打开** (file://) 重复上面这条, 看浏览器
  弹不弹选择器; 同时回归 ① (本地服务) 的行为不变。
  版本显示单独一条 (两条路都走): 连上后在状态栏看到两个版本 → 断开 → 刷新开始页,
  两行版本还在 (直连态靠 localStorage, 服务端态靠服务端重发)。

### 固件烧录 (开始页与调试页都能开)

面板列出检测到的 RP2040 (应用模式 / BOOTSEL)、桥接状态、可烧录固件 (编译产物,
或从浏览器选本地 .uf2), 一键烧录并实时回显 picotool 输出。入口是开始页的
「烧录固件…」—— 面板在两个页面之外 (固定定位的 overlay), 不必先连接就能刷固件。

- **为什么烧录也在服务端**: Pico 插在跑服务的那台机器上, 浏览器够不着那侧的
  USB —— 与「为什么必须服务端桥接」同一个理由, 所以不做 WebUSB。命令是本机
  执行的, 走 `subprocess` 参数列表, 不经过 shell。
- **用 picotool 而不是自己实现 BOOTSEL 流程**: `load -f -x <uf2>` 一条就覆盖
  「请求运行时固件软复位进 BOOTSEL → 写入 → 重启回应用」, 所以设备即使在应用
  模式也能直接烧, 不必手动按 BOOTSEL 键。⚠️ `picotool reboot -f` 是**静默空
  操作** (--force 只让命令得以执行, 而 reboot 会把设备送回应用模式), 要真重启
  就用 `load -f -x`。
- **设备检测** 读 `/sys/bus/usb/devices/*/idVendor` 认 2e8a, PID 000a=应用 /
  0003=BOOTSEL。不依赖 lsusb/pyusb/udev。
- **路径白名单**: `/flash` 只接受解析后落在 `pico/build/` 或本次上传目录内的
  `.uf2` (这是全项目唯一一处"用户输入决定读哪个文件"的地方)。
- 找不到 picotool 时用 `HEXAPOD_PICOTOOL` 环境变量指定; 面板会明示不可烧录。

轮询 `!BATT`/`!IMU`/`!A`/`!I2C q`/`!PERIPH` (各带 `--*-interval` 秒, 0=关; 外设
那条是 `--periph-interval` 默认 2.0 —— 外设状态固件不主动推, 只能问), 可暂停。
遥控门心跳 (`!RC 0`, `--rc-interval` 默认 2.0) 不是轮询: 它只维持锁定, 暂停轮询
时照发 —— 否则一暂停机器人就被固件超时解锁。
URL 带 `#gait`/`#ctrl`/`#calib` 等页名可直接落到某一页; 认不出的页名 (如旧书签
`#params`) 回落到状态页。

**I2C 卡片为何用 `!I2C q` 而不是 `!I2C`**: 命令处理跑在固件的 20ms 控制循环内
(`hal_input_update` ← `hexapod_update`), 所以一条命令的耗时 = 舵机停更时长。健康
总线上两者都是 ~20ms, 但总线被拉死时每次 I2C 事务吃满 `PCA9685_I2C_TIMEOUT_US`,
`!I2C` 的 128 地址全扫描最坏累计 640ms —— 轮询用只做定向检测的 `!I2C q`, 全扫描
留给校准页手动 `!I2C` 按钮。每次检测的起始头行 (`=== I2C Bus Check …`) 用于作废
上一轮设备状态, 否则掉线的设备会永远留在卡片上; 扫描列表只在全扫描时清, 免得
手动扫出来的结果 3 秒后被轮询抹掉。

**外观**: 照搬 Betaflight Configurator 的设计语言 (`betaflight-configurator/src/css/theme.css`
+ `main.less`) —— 琥珀主色 `#ffbb00`、中性灰表面色阶、12px 字号、20px 紧凑控件、
左侧胶囊标签页、圆角描边分组框 + 悬浮胶囊标题、底部工具栏与状态栏。深色单主题,
不跟随系统。

### 运行时参数 (Phase 2, 2026-09)

改参数不再需要重编译重烧。92 个可调项分 12 组: 电池 / 运动 / 站立姿态 /
几何 / 手感死区 / 方向取反 / IMU / 通道映射 / 模式 (矩阵 + 组合键) / 系统 / 外设 / 端口 ——
每组对应网页的一个参数页 (见上表, 遥控页含 tune/dir/chan 三组, 模式页是 modes 组
的自定义控件, 系统组目前只有 loop_ms)。

**两类参数的分界** (改代码前先想清楚这条):

- **运行期可调** — 手感、阈值、行程、开关这类"会想现场试"的量。在
  `hexapod_config.h` 里写成 `#define X (g_params.x)`, 默认值保留为 `X_DEFAULT`;
  调用处一个字都不用改, 宏把编译期常量透明换成了运行期变量。
- **编译期常量** — 引脚、舵机 ID 表、36 项舵机软极限 (SERVO_*_MIN/MAX)。这些改动
  等于换机器, 留在 `#define`, 也避免运行期被误改。
- **几何 (geo 组) 居中** — 腿长、站高、舵机零位、安装角、机身/足端偏移已是运行期
  参数, 但**只在启动时读一次** (`params_load()` → `robot_init()` →
  `hexapod_get_default_config()`), 所以页面上写明「重启后生效」。不热重建的原因:
  这些量构造出的 leg_configs 在运行中被平衡旋转与站姿缩放反复改写, 热重建等于
  在飞行中换腿。18 路 `horn_offset` 仍走校准 (`!HO` 网页面板 / `!C` 走查, 再 `!SAVE`
  落盘), 不进参数表 —— 校准值按 `done_mask` 覆盖参数里的默认值, 优先级不变。

参数表在 `hexapod_params.c` (`param_t`: 名字/指针/min/max/默认/单位/组)。
`params_init()` 在启动时校验**表项数 == 结构体字段数**并检查名字长度 —— 漏加表项
的参数是"静默不可调"的 (网页上表现为改了没反应), 这类 bug 只能靠启动时报出来。

**名字长度有两处硬耦合**, 改动任一处都要同步 (测试 `[2] 固件契约` 会挡住):

- `STORE_PARAM_NAME_LEN` (20) — flash 记录与命令行缓冲的长度; 名字超长会被截断成
  另一个名字, 存了等于没存。最长现名 19 (`body_offset_x_front`), 只剩 1 字节余量。
- `tools/webconfig/server.py: PARAM_NAME_OK` — 服务器按同一上限校验。

**串口命令行缓冲 `SERIAL_CMD_BUF` (48 字节)**: 参数命令带名字带值, 最长约 36 字节。
旧的 16 字节缓冲会把 `!CFG batt_interval_ms 5000` 悄悄切掉尾巴 (表现为"改了没反应"),
现在**超长命令整条丢弃并报错**而不是截断 —— 截断后可能正好撞上另一个合法名字。
`tools/serial_console.py: MAX_CMD_LEN` 必须与它一致 (47)。

#### 命令

| 命令 | 作用 |
| --- | --- |
| `!CFG` | 列出全部参数 |
| `!CFG <name>` | 查询一个 |
| `!CFG <name> <value>` | 设置 (回显实际生效值; 越界时先打 WARN) |
| `!CFGR [name]` | 恢复默认 (无参 = 全部) |
| `!CFGW` | 存 flash (仅未解锁时; 用 `!S` 先停) |

> 命名避开 `!P` 家族: `!P<id> <angle>` (舵机直控) 与 `!PER` 已占用该前缀,
> `!PL` / `!PS` 这类靠长度区分的写法迟早撞车。`!CFG` 家族无冲突且自解释。

#### 输出格式契约

```text
[P] name=travel_fwd_mm val=150 min=20 max=250 def=150 unit=mm grp=motion chg=0
```

`server.py` 的正则依赖 `key=value` 全为无空格 token (`unit=` 为空时就是空 token)。
改 `params_print_one()` 必须同步 `server.py` + `test_webconfig.py`。

#### 落盘

- 参数记录在 flash 扇区 `0x1FD000` (与校准 `0x1FE000`、事件日志 `0x1FF000` 并列)
- 按**名字→值**存, 不按索引: 固件升级增删表项后旧记录仍能落到正确参数上,
  表里没有的名字直接跳过并计数 (`[PARAM] Loaded N params from flash`)
- **只存非默认值** —— 换板改 `config.h` 默认值后, 旧记录不会把新默认压回去
- 记录变大/改布局时递增 `STORE_PARAMS_VERSION`; 版本不符的记录**整体忽略**
  (参数回退到 `config.h` 默认值)。当前版本 4: 条目数嵌在结构体里、CRC 覆盖
  全结构, `STORE_PARAMS_MAX` 扩到 96 (容下全部参数) 即改布局, 故旧记录作废
  (v3 及更早的记录第一次上电即失效, 参数回到出厂默认, 需要重新 `!CFGW`)。
  三个扇区各自独立版本:
  参数记录失效**不影响**校准记录 (`0x1FE000`, 版本 1) 与事件日志 (`0x1FF000`),
  旧固件写下的校准值照常载入
- 反过来, **只在高位加位不算改布局**: `mode_*` 的单击位在 bit8、`combo_*` 的按住位
  在 bit10, 低 8/10 位一个没动 —— 旧 v4 记录载入后解码结果逐位相同 (高位读 0 =
  旧语义), 所以加这两个功能时**没有**升版本, 也不该升 (升版只会白丢用户已存的配置)。
  新写入的大值被旧固件读到也不出错: 高位被静默丢弃, 行为退化成加位之前
- 记录页用 `_Static_assert(STORE_PARAMS_RECORD_BYTES <= 4KB)` 把关; 表项数也由
  测试对着 `STORE_PARAMS_MAX` 校验 —— 参数表超过上限会被**静默截断** (存了等于没存)

#### 前端行为

参数表只在**点「连接」/ 桥接重连 (已连接时补拉) / 用户点「读取」**时拉取
(92 行打印会淹没串口; 停在开始页时一次都不拉)。
滑块松手才下发 (拖动中只更新数字框), 否则 100Hz 控制环会被命令洪水淹没。
写值后以**固件回显**为准刷新页面 —— 越界值时前端显示的是被夹住后的实际值。
每页顶栏的统计是**本页**的 (参数数 / 未保存的改动数), 不是全局的。

**两个按钮看的是两件事, 别混**: 「保存到 Flash」看「有没有改过」(与上次存盘比),
「本页恢复默认」看「有没有偏离默认」(与出厂默认比)。刚从 flash 载入的非默认值
属于前者已持久化、后者该点亮 —— 一个只按 `chg`(≠默认) 判断的保存键会一开页
就亮着, 压下去只是空写一次 flash。

未保存的判定是纯前端的: 按参数记一条基线 (`pBase`, 初次见到时填入 —— 那一刻
生效值即 flash 值), 固件回 `[STORE] Params saved OK` 时整条重建, 所以从日志页
命令框手敲 `!CFGW` 也能把按钮按回去; 反过来被固件拒 (robot is armed) 时基线不动,
未保存标记不会被误清。固件侧没有 dirty 标志 —— 加了就得改线上格式, 而需求本来就是
每页一份的, 全局标志还得再拆。已知缺口: 参数在页面载入**之前**被串口侧改过的话,
基线会把它当成已存盘。

#### 校准页

三张卡, 页内以"入口 + 状态显示"为主 (逐舵机定中心是例外, 见下):

- **舵机**: 卡上是 18 格角度 (与状态页同一份数据, `renderServo` 刷两处), 每格
  显示这一路当前的 `horn_offset`。点格子选中 → 面板出现 (已选路 / 当前偏移 /
  滑条与数字框 / ±5° ±20° 微调 / 「设为中心」): 滑条与微调发 `!P<id> <ang>` 直接
  转舵机, 「设为中心」发 `!HO <id> <ang>` 把当前角度记成机械中心 —— 写入立即生效,
  不必重启, 全部调完再 `!SAVE` 落盘。`!HO` 不在参数表里 (校准值不是参数), 因此
  走**另一条命令** `!SAVE`, 而不是参数页那个「保存到 Flash」(`!CFGW`)。
  另三个快捷按钮 (`data-cmd` → `/cmd`, 没有服务端解析环节): `!C` 走查 /
  `!SAVE` 保存校准 / `!I2C` 扫描总线; `!C` 本身是从串口命令框驱动的一串交互
  (`!C` → `!+/-` → `!S` → `!Q`), 回显 (`Saved OK (18 servos, …)` / `Refuse: …`)
  直接落在日志页, 配色已由 `classify()` 覆盖。
- **电压标定**: 没有新命令, 也没有新参数 —— 它在**页面侧**算一个已有参数:
  `分压比 = 万用表实测电池电压 ÷ ADC 引脚电压` (`pin_mv`, 与分压比无关的基准量),
  填完点「按实测标定」就按这条式子算出 `batt_ratio_milli` 并走 `sendSet` 下发
  (与「电源」页那根滑条同一个参数、同一条通道), 掉电保持仍是「保存到 Flash」。
  未接电池 (`ABSENT`) 或引脚读数无效时按钮置灰。固件只提供数据, 不参与换算。
- **IMU 校准**: 标定值归 BNO055 自己维护, 页面显示 `!IMU` 帧里的四级校准等级、
  在线状态与 Roll/Pitch (与状态页同一份数据, `renderImu` 同时刷两处), 重置按钮是
  固定命令 `!IMUR` (整芯片复位 + 重新初始化, 见「IMU 姿态补偿」一节)。因为 `!IMU`
  已被 server 按 1s 轮询, 点完不用手动刷新就能看到等级从 0 重新爬升。

### 设计约定

- **默认只绑 127.0.0.1**: 网页能驱动真实机器人, 暴露到网络等于把机器人交出去;
  远程访问一律走 SSH/VSCode 端口转发。`--host 0.0.0.0` 会打印警告。
- **轮询仅在"有浏览器连着 + 处于连接态 + 未暂停"时进行** —— 空闲或停在开始页时
  都不打扰共享的串口总线。
- **解析在服务端**, 前端只渲染: 固件输出 → 正则 → JSON 事件 → SSE。
  未匹配的行原样进日志面板, 所以**固件新增输出不会弄坏页面**, 只是不显示。
- 遥测解析依赖固件输出文本, 改格式要同步 `server.py` 正则 + 测试里的逐字样本
  (`test_webconfig.py` 的 `S_BATT`/`S_I2C`/`S_IMU`/`S_SERVO`)。
- **raw 白名单只放高频行**: `[HW]` 与 IMU 那四条传感器行不在里面, 与既有 IMU 行
  同待遇 —— 解析成帧之后照样落在日志面板。真要治它得等 `!TEL` 定频帧 (那时这些
  行本来就该降频)。高频**块**(`!IMU` 状态块) 另有一套折叠, 见「IMU 状态块整块折叠」。
- **解析器有两份, 必须同时改**: `server.py` 与 `index.html` 各一份 (① / ②)。
  `test_webconfig.py [6]` 拿同一条时间线逐帧差分, 并逐条比对两边共有的正则模式体
  (字面量直接比字符串) —— 只改一边会在这里变红, 不会变成"两种打开方式显示不一样"。
- **藏元素用 `hidden` 属性就够了** (样式表顶部有一条 `[hidden]{display:none!important}`
  兜底), 但**别给同一个元素再写 `display`** —— 作者样式会盖掉浏览器默认的
  `[hidden]{display:none}`, 于是 `el.hidden = true` 看着设了却没藏住: 直连态还显示
  「串口桥接」就是这么漏出去的。测试按 `getComputedStyle().display` 校验, 不看属性。
- 已知真机行为: 未解锁时舵机断电 (GP10/GP11=0), 此时 PCA9685 读数不可信、
  舵机角度全 0; I2C 扫描必现 `0x70` —— 那是 PCA9685 的全呼叫地址 (ALLCALL
  默认开启), 不是神秘器件。

### 路线图

**Phase 2 配套 A —— 定频遥测帧**
现在只有事件触发打印, 画不出连续曲线 (状态总览那五张 IMU 曲线是诊断帧的过渡方案,
5 Hz 采样 —— 看得出趋势, 看不出波形)。加 `!TEL <hz>` 输出 CSV 行
(`T,<ms>,<vbat>,<roll>,<pitch>,<yaw>,...`), 20~50Hz。USB CDC 带宽充裕
(12Mbps), 不需要二进制协议。⚠️ 必须走主循环**非阻塞**路径 + 有界队列,
满了丢帧并计数 —— 绝不能阻塞 100Hz 控制环。

**Phase 2 配套 B —— 结构化响应**
加 `!J 1` 切换 JSON 行输出, 免掉前端正则解析 (现阶段正则是权宜之计, 脆弱)。

**直连模式的边界 (不是缺陷, 是不做的)**
烧固件仍只在 ①: Web Serial 够不着 BOOTSEL 那套 (要另做 WebUSB 协议, 而 uf2
拖盘已经够用)。Firefox 151 起才支持 Web Serial, Safari 至今不支持 ——
这两种浏览器上退回 ① 或换 Chrome/Edge。

**Phase 3 —— 交互页**
- 舵机测试页 = Betaflight 的 Motors 页 (校准页已有单路滑条与微调, 但一次只看一路、
  也没有 `!W` 扫摆与批量回中, 尚不成一整页)
- 日志查看器 (`!LOG` flash 事件日志, 带时间轴)

## IMU 功能路线图 ★设计草案 (2026-08)

> BNO055 尚有大量能力未用, 按对机器人的实际价值分层规划。
> 各阶段独立, 可单独实施与验证。

### Phase A: 补偿健壮性 (改动集中在 bno055.c / hal_imu_read)

- **A2 重力矢量替代欧拉角**: BNO055 输出重力矢量 (gravity x/y/z),
  atan2 求倾角 — 无奇异点、无翻转问题, 任何安装方向都稳。
- **A3 校准门控**: sys 校准 < 阈值时补偿不生效 (offset=0),
  达标后自动启用 — 防止未校准垃圾姿态注入补偿。

### Phase B: 动态性能

- **B1 D 项阻尼 (PD 补偿)**: 用 BNO055 陀螺仪角速度加微分项:
  `offset = −(角度×Kp + 角速度×Kd)`, 阻尼落地冲击/爬台阶振荡。
  当前实现是纯 P (增益1), 动态地形无阻尼。

### Phase C: 安全保护

- **C1 防翻倒检测**: |roll| 或 |pitch| > 45° 持续 > 300ms + 角速度突变
  → 紧急停止 + 舵机去扭矩 (翻倒后 18 舵机乱蹬是烧舵机主因之一)。
- **C2 撞击检测**: ACC_HIGH_G 中断 → 撞击瞬间断舵机供电。
  无需物理 INT 引脚 — 中断标志锁存, 100Hz 经 I2C 轮询 INT_STA 寄存器即可捕获。

### Phase D: 地形与航向

- **D1 地面坡度估计**: pitch/roll 低通滤波 → 坡度;
  爬坡降重心/加宽站距, 下坡后倾保持。
- **D2 滑移检测**: 有行走指令但加速度计无位移 (或航向漂移)
  → 足端打滑 → 减速/换步态。
- **D3 航向保持 (走直线辅助)**: 摇杆 yaw 中位 + mag 校准完成时,
  慢速外环修正 heading 漂移 (机械不对称/打滑/重量不均造成的偏航):
  `修正量 = clamp(K×航向误差, ±小限幅)`, ~1~2Hz, 大滤波。
- **D4 偏航扰动响应 (突变外旋)**: ★用户提议, 待细化
  - 检测: 陀螺仪 yaw 角速度突变 (外部突然旋转: 被撞/踢/腿卡障碍)
  - 扰动状态: 冻结步态 (不抬腿) + 机身直接反向 yaw 旋转抵消,
    限幅 ±30° 防过度扭曲腿部
  - 退出: 扰动结束 (角速度回落) → 恢复步态;
    累计旋转超限 → 碎步缓慢转回
  - 与 D3 配合: D3 管慢速漂移, D4 管突变扰动, 均不与操作员冲突
    (操作员一动 yaw 摇杆即退出)

### 明确放弃 (对六足无价值)

| 功能 | 理由 |
|---|---|
| 温度输出 | 不关心芯片温度 |
| 低功耗/挂起模式 | 行走机器人无待机场景 |
| 加速度量程切换 | 默认 ±4g 足够 |

### yaw 现状说明

- 当前 yaw 不补偿的原因: 磁航向室内噪声大 (18 舵机 PWM 磁场干扰) +
  与操作员转向指令冲突 + 磁校准未完成时漂移
- 将来的 yaw 策略 = D3 (慢速航向保持) + D4 (突变扰动响应),
  不做连续 yaw 补偿 — 彻底避开磁噪声与操作员冲突

## 地形适应设计 (IMU + 足端开关) ★设计草案 (2026-08)

> 目标: 让机器人适应未知地形 — 越过障碍物、上下台阶、斜坡行走。
> 实现目标和步骤尚未最终确定, 本文档为设计讨论的沉淀, 供逐步细化。

### 传感器角色

| 传感器 | 提供 | 回答 |
|---|---|---|
| IMU (BNO055) | 机身绝对姿态 | "机身现在斜了多少?" |
| 足端开关 ×6 | 每条腿的触地事实 | "这条腿碰到地面了吗?" |

现有 IMU 补偿只回答"如何调平", 无法回答"腿有没有着力" —
被拿起/翻倒时调平动作全部落空。足端开关恰好补齐这一环。

### 三个核心机制

#### ① 寻地式落腿 (基础机制, 取代盲降)

```
抬腿 → 前摆到目标位置 (保持最大高度)
     → 缓慢下放
     → 开关触发? → 立即锁定为支撑腿 ✓ (不再继续下放)
     → 下放到机械极限无触发? → "此处无地面" → 空洞检测 (机制③)
```

每条腿独立适应地形高度 — 台阶/砖块/斜坡无需预知。

#### ② 悬空检测 (解决"被拿起乱蹬")

```
条件: 6 开关全未触发 且 IMU 姿态突变/超阈值 (如 |roll|>45° 或 |pitch|>45°)
→ 判定: 机器人悬空 (被拿起/翻倒)
→ 动作: 冻结步态 + 暂停 IMU 补偿 (空中调平无意义)
恢复: 开关重新触发 → 恢复步态
```

#### ③ 空洞/悬崖检测 (①的副产品)

- 腿下放到极限无触发 → 前方空洞/悬崖
- 策略: 不向该腿转移重心 → 后退换向, 防止走下桌沿

### 爬楼梯推演

```
1. 前腿前摆 + 寻地式落腿 → 开关在台阶面上触发 → 落在台阶上
2. 身体前移 → 机身仰起 → IMU pitch ↑
3. 中腿寻地落上台阶 → 后腿依次跟上 → 机身回平
4. 逐级重复, 无需知道台阶高度/数量
```

关键调控: 爬升时允许机身暂时倾斜 (姿态包络, 不追求绝对水平),
仅限制倾斜上限 (防翻倒) — IMU 的角色从"死守水平"变为"包络控制"。

### 分阶段实现计划 (草案, 待细化)

| 阶段 | 内容 | 预估改动量 |
|---|---|---|
| P1 | 寻地式落腿: 开关接入步态引擎摆动相 | 中 — 摆动相改为"前摆保高 + 下降寻地"两段式 |
| P2 | 悬空检测 + 步态冻结 (IMU 突变 + 全开关悬空) | 小 — 核心循环加状态判断 |
| P3 | 空洞检测 + 后退策略 | 小 — P1 副产品 |
| P4 | 爬升姿态包络 (倾斜上限 + 越障减速) | 中 — 需实测调参 |

### 开放问题 (未定, 待实现前确认)

- [ ] 爬升时允许的最大倾斜角? (建议 20°~30° 起步)
- [ ] 寻地式落腿的下放速度曲线? (快速接近 + 减速触地 vs 匀速)
- [ ] 空洞检测: 全局后退 vs 局部绕行?
- [ ] 开关机械安装: 足底触地即合 vs 悬垂触发? (影响响应时延)
- [ ] 触地响应时间目标? (决定开关消抖方案)
- [ ] 是否保留现有固定步态序列, 还是摆动相全部改造?

### 风险与容错

- 开关抖动 (~5ms): 10ms 控制周期下需连续 2 次读取一致才采信
- 开关卡死(恒"触地"): 该腿永远认为落地 → 下放距离限制兜底
- 开关断裂(恒"悬空"): 寻地到机械极限后按原盲降逻辑执行
- 寻地时延: 用"上周期地面高度"预测起始点, 先快速下放再减速寻地
- 腿部走线: 足端开关线缆随腿运动 → 硅胶线 + 应力释放

## 引脚/资源映射存 Flash (免重编换接口) ★设计草案 (2026-09)

> 目标: 换底板、换接线、换舵机板地址之后, **只动配置** (网页或串口) 就完成接口
> 功能转换 —— 不改代码、不重编译、不重烧固件。现在只有 6 组"开/关"搬进了参数表,
> 引脚归属本身仍是散在四个文件里的编译期宏。本文是把整张引脚表搬进 flash 的设计
> 草案, 分阶段、待细化。

### 现状: 哪些已经是配置, 哪些还是代码

**已经是运行期参数** (改完即时生效, 「保存到 Flash」掉电保持):

| 项 | 参数 |
|---|---|
| 外部 UART0 开/关 + 波特率 | `uart0_en` / `uart0_baud` |
| 输入源 + 串口模式波特率 | `input_mode` / `input_baud_serial` |
| 电机 GP2/3 是 PWM 还是 GPIO | `dc_motor_en` |
| 足端 GP16-21 是检测还是 GPIO | `foot_sw_en` |
| 外部排针 GP26/27 干什么 | `ext_i2c_mode` |
| 板载三脚 GP23/24/29 输入/输出 | `gp23_fn` / `gp24_fn` / `gp29_fn` |

⚠️ 这六组只给"开/关 + 波特率", **不给换脚** —— `hexapod_config.h:944` 写明了理由:
UART/I2C 的引脚归属被当作硬约束, 端口页对它们只提供开关。本草案要做的正是把这条
约束从"代码"挪到"配置 + 校验"。

**还是编译期常量** (改一处要重编; 且分散在四个文件里, 今天没有单一"引脚表"):

| 硬件 | 引脚 / 地址 / 编号 | 定义处 |
|---|---|---|
| 舵机 I2C 总线 | `i2c1` @400kHz, GP14 SDA / GP15 SCL | hexapod_i2c_protocol.h:19-22 |
| PCA9685 地址与板数 | 0x40 左 / 0x41 右, `PCA9685_BOARD_COUNT 2` | hexapod_i2c_protocol.h:27-28, hexapod_config.h:303 |
| 舵机 id → 板 / 通道 | id = 腿×3+关节; id 0-8 → 0x41, 9-17 → 0x40 (PCB 定版) | hexapod_hal_pico.c:267-276, 2391; hexapod_i2c_protocol.c:248-257 |
| 空闲 PWM 14 路编号 | 0-6 左板 / 7-13 右板, 物理通道基址 0 / 9 | hexapod_config.h:995-1001 |
| IMU 地址 | BNO055 @0x29 (bno055.c 里有地址变量, 但只被宏赋值) | hexapod_config.h:209 |
| 时序 / 频率常量 | CRSF 420000、I2C 400kHz/5ms 超时、电机 PWM 10kHz、PS2 8µs 半周期、PCA9685 周期默认 9500µs | hexapod_hal_pico.c:555-556, 632; hexapod_i2c_protocol.h:20, 23, 63-64; hexapod_ps2.h:38 |
| 舵机电源 | GP10 左 / GP11 右 | hexapod_hal_pico.c:508-509 |
| 直流电机 | GP2 / GP3 | hexapod_hal_pico.c:553-554 |
| 输入 UART1 (CRSF/PS2) | GP4 TX / GP5 RX | hexapod_hal_pico.c:627-628 |
| 足端开关 ×6 | GP16 ~ GP21 | hexapod_hal_pico.c:2750-2755 |
| LED | GP25 绿 / GP12 红 | hexapod_hal_pico.c:2839-2840 |
| 蜂鸣器 | GP13 (PWM6B) | hexapod_config.h:877 |
| 外部 UART0 | GP0 TX / GP1 RX | hexapod_config.h:894-895 |
| 外部 I2C/ADC | GP26 / GP27 (软件位翻转或 ADC0/1) | hexapod_config.h:921-924 |
| PS2 四线 | GP6-9 (DAT/CMD/SEL/CLK) | hexapod_ps2.h:31-34 |
| IMU BOOT | GP22 | hexapod_config.h:235 |
| 电池 ADC | GP28 (ADC2); 分压比已是参数 `batt_ratio_milli` | hexapod_config.h:130-131 |

### 为什么不是在参数表里"再加十几项"

1. **约束表达不了**: 参数是 (名字 → int32), 说不了"这个功能只能落在哪些脚上"
   (RP2040 多路复用表)、"TX/RX 必须同实例同组"、"I2C 必须成对"、"同一 PWM 切片的
   两脚共用频率"、"ADC 只有 GP26-29 四路"。这些约束现在是**代码里的事实**, 搬进
   配置就必须同时搬一套校验, 否则配出来的表是"能存下来但跑不起来"的;
2. **容量**: 参数表已 92/96 项, 记录 2316B 占掉单扇区的 57% (hexapod_store.h:57, 88)。
   十几个引脚勉强塞得下, 但舵机通道映射、板地址、UART 实例这些结构性信息塞不进去;
3. **每加一项仍要改三处代码** (params.h 字段 / config.h 宏 / params.c 表行) 再重编
   —— 与目标相悖; 资源表加一项是加一个枚举值, 页面自动跟着变。

### 数据模型 (草案)

两张表, 分工写死:

- **资源表 (引脚 → 功能)**: 逐引脚固定 30 条 (GP0~GP29), 每条 2 字节
  `{ func, flags }` —— 固定长度、无名字, 与"名字→值"的参数记录不同, 因此走
  独立扇区 (`0x1FC000`, 现空), magic / version / crc32 照抄校准记录的写法
  (hexapod_store.h:64-74)。功能枚举带实例号 (如 `FUNC_UART1_TX`), 不在表里存实例;
- **功能 → 参数**: 波特率、I2C 速率、PCA9685 地址/通道映射这类"带数量"的东西
  留在参数表 (已有 `uart0_baud` / `input_baud_serial` 先例), 资源表只管"哪根线
  接什么"。
- **这套机制不是新发明, 是推广两条现成先例** —— ① PWM 周期已经走"编译期默认
  (hexapod_i2c_protocol.h:63-64) + flash 覆盖 (hexapod_store.c:277) + 运行期设置
  (hexapod_i2c_protocol.c:273-290)"三级结构; ② PCA9685 的板地址本来就是上电扫
  候选表探出来的 (hexapod_i2c_protocol.c:27, 109-136), 板数运行期可变。资源表把
  同样的"默认在代码、真值在 flash、启动时应用 + 探测降级"搬到引脚上。

第一版功能枚举 (草案): `NONE` / `FREE` (普通 GPIO, 收编现有 `gpXX_fn`) /
`UART0_TX|RX` / `UART1_TX|RX` / `I2C0_SDA|SCL` / `I2C1_SDA|SCL` /
`SERVO_PWR_L|R` / `MOTOR1|2` / `FOOT_RR|RM|RF|LR|LM|LF` / `LED_R|G` /
`BUZZER` / `ADC0|1|2|3` / `IMU_BOOT` / `PS2_DAT|CMD|SEL|CLK`。

### 校验: 能力表 + 冲突检查

- **能力 (硬约束)**: 固件里一张静态表, 由 RP2040 多路复用表推出 —— UART0 只能落
  GP0/1、GP12/13、GP16/17; UART1 只能落 GP4/5、GP8/9; I2C0/I2C1 各自的引脚组;
  ADC 只有 GP26-29; PWM 每切片两脚 (GP2n / GP2n+1) 共用频率; GP23/24/29 板载占用
  (见「端口页 (引脚归属)」)。违反 → 拒绝该条并说明理由;
- **冲突**: 同一脚两个功能 / 同一实例被要两次 / TX 与 RX 不同组 / I2C 不成对 /
  两路 PWM 落同一切片 —— 报错要点名冲突对方 (Betaflight 的 resource check 就是这样);
- **分两级处理**: 能力与冲突是**硬**的 (拒绝保存); "配置与实测硬件不符" (I2C 上扫不到
  PCA9685、ADC 读数离谱) 只**报警告**, 在端口页红字显示, 不拦解锁 —— 否则一块没插的
  扩展板就能让机器人拒绝启动;
- 校验时机: 启动时一次 (应用配置前) + 改一条就校验一次 (即时反馈)。

### 页面 (数据驱动)

- 固件新增 `!RES` (打印资源表) 与 `!RESCAP` (打印能力表: 每个功能可落在哪些脚),
  网页「端口」页据此渲染下拉。现在页面里大约二十处引脚硬编码 (8 行表格 + 4 行固定脚
  + 每行 hint 与若干 note 文本, 见 index.html:1842-1908), 换板就得改页面;
- 保存流程复用参数那套: 改 → 即时生效 → 「保存到 Flash」落盘; 「恢复默认」回出厂表;
- **导出/导入**: 一份纯文本的 `resource dump` (像 Betaflight 的 diff), 换板时贴进
  串口命令框或配置器就能复刻整套接线, 也方便进 git 做版本管理。

### 分阶段实现计划 (草案, 待细化)

| 阶段 | 内容 | 预估改动量 |
|---|---|---|
| P1 | 资源表 + 校验器 + `!RES`/`!RESSET`: 先把**现有**映射原样搬成表 (值等于现状, 行为零变化), 只做存储与打印 | 中 — store 加一条记录 + hal 收敛引脚宏 |
| P2 | 端口页改读 `!RES`/`!RESCAP` 渲染, 删掉页面里的引脚硬编码 | 中 — 页面重画 + server 加帧 + 契约测试 |
| P3 | 真正放开换脚: UART/I2C/ADC/PWM 功能可选脚, 校验器拦非法组合 (含"舵机总线换 I2C 实例") | 大 — 每类外设的 apply/detach 都要能与配置表对齐 |
| P4 | 结构化映射也进配置: PCA9685 地址表与板数 (扫描式)、舵机通道映射、空闲 PWM 编号 | 中 — 影响 i2c_protocol 与网页外设页 |
| P5 | 配置档案导出/导入 + 换板迁移步骤写进文档 | 小 |

### 救援: 配置改坏了怎么办

- 资源表独立扇区 + CRC + 版本: 坏了整体回默认 (与参数记录同一策略, 见「落盘」一节);
- **固件永不依赖配置才能启动**: 上电先按安全态初始化 (输出全低、舵机电源断),
  校验通过后才应用配置;
- 保留一条不依赖配置的救援路径: USB CDC (RP2040 内核固定, 不占 GPIO) 里
  `!RESSET` 恢复出厂表; 再不行还有 BOOTSEL 重烧;
- 保存资源表后提示重启自检一次 (Betaflight 保存后也要重新上电), 自检结论回显到页面。

### 仍然必须重编的部分 (边界)

- 新增**种类**的设备或协议 (新传感器、新外设) —— 永远要代码;
- 换 MCU / 换板型 (RP2040 → RP2350; Pico W 的 GP25/GP29 被无线占用, 与板载脚表冲突);
- 构建变体 (`INPUT_CONTROL_MODE` 的 USB/PS2/CRSF、`PS2_ENABLED`、`HEADLESS_MODE`、
  `USB_DEBUG_ENABLED`、`IMU_BOOT_GPIO_ENABLED`) —— 这些是"编不编这段功能",
  与引脚无关, 保持编译期;
- flash 扇区布局与三种记录的格式改版。

### 风险与容错

- 半配置状态: 改到一半掉电 → 整表一笔写 + CRC (现有写法), 不会出现半张表;
- 误配伤硬件: 把电机 PWM 配到舵机电源脚这类组合, 能力表拦不住 (两脚都合法),
  靠"上电安全态 + 解锁前自检 (舵机电源脚电平回读)"兜底;
- 固件长大撞存储区: 存储区在 flash 末尾, 现在 text ≈102KB, 离 `0x1FC000` 还远,
  但没有链接期断言拦着 —— 值得补一条 (现在只有记录大小与扇区宽度的静态断言);
- 复杂度回流: 校验器、页面、测试三处都要跟着功能枚举长 —— 加功能时忘了改页面,
  表现为"新功能在页面里选不到", 用契约测试钉住 (现有 `WEB_GROUPS` / 参数覆盖
  那几条就是同一套路)。

### 开放问题 (未定, 待实现前确认)

- [ ] 资源表粒度: 逐引脚 (30 条, 直观) vs 逐功能 (紧凑, 但要处理"多个候选脚")?
- [ ] 允许同一功能多实例吗 (两路蜂鸣器 / 两组 LED)?
- [ ] 校验失败的粒度: 整表拒绝 vs 只丢坏条目 + 警告? (草案倾向后者)
- [ ] 解锁前是否强制自检, 还是只在端口页标红?
- [ ] 要不要"扫描式自动配置" (探测 I2C 上的 PCA9685 地址, 自动填表)?
- [ ] `gpXX_fn` 被 `FUNC_FREE` 收编后, port 组那几个参数是删还是留作快捷开关?

## 待完善
- [ ] ★ 网页服务加鉴权 (可选 token 或反代 basic auth): 现在零鉴权 —— 能连上网页的
      人就能解锁、驱动舵机、烧固件。今天靠"只听 127.0.0.1"兜底; 要让局域网外也能开
      (`--host`), 或者在反向代理/内网穿透后面公开, 必须先有这道门。
      (私有网如 Tailscale 不在此列: 访问控制由网络层做, 够了)
- [x] 用 !C 实测每条腿的 horn_offset (已完成: 18 路标定值固化在 hexapod_config.h 各腿 *_horn_offset)
- [ ] 用 !W 实测舵机机械极限, 收紧 SERVO_xxx_MIN/MAX
- [ ] GP29/ADC3 读 VSYS (板载 200k/100k 分压已接好, 固件没读): 现在端口页只能
      看到恒 0 的数字电平, 读 ADC3 才能报"VSYS 几伏 / 电池轨在不在"
- [x] 用 !PER 实测两块 PCA9685 的 PWM_PERIOD_US 并填入 hexapod_i2c_protocol.h (已完成: 9500/9500)
- [ ] ADC 分压电路实测 (通过后 `!CFG batt_check 1` + `!CFGW`)
- [x] 参数存储实机验证 (2026-09-27, 2MB flash 实测):
      `!CFG travel_fwd_mm 180` → `!CFGW` 见 `Params saved OK (1 项, CRC …)` →
      `picotool reboot -f` 复位 → 读回 `val=180 chg=1` → `!LOG` 见 `PARAM_SAVED` →
      `!CFGR` + `!CFGW` (0 项) 清回默认。⚠️ 名字长度修复前此路径必然静默丢值
- [ ] ★ 非易失存储硬件冒烟 (校准部分, 固件已构建通过, 待实机验证):
      `[STORE] Flash storage init` 启动行 → `!C` 调 2 路舵机 → `!SAVE` 见
      `Saved OK` → **断电重启** → `[STORE] Calibration loaded` → `!A` 确认偏移生效
      → `!LOG` 见 2×BOOT + CALIB_SAVED → `!LOGC` 清空 → 解锁后 `!SAVE` 应被拒
- [ ] 查证事件 3 旧板: 损坏 FET 失效模式 (G-S 短=栅氧击穿; G-S 完好+D-S 短=热击穿/雪崩)
      + 大铜箔与电池负极的实际连接宽度
- [ ] 接地实测验证 (先测后下结论):
      ① DMM 测旧/新板满载 (舵机全动或堵转一只) 时大铜箔对电池负极的 DC 电位差
      ② 新板电池 ADC 负载下读数 vs 万用表实测 (通过 → `!CFG batt_check 1` + `!CFGW`)
      ③ (有示波器时) 堵转/插拔瞬间测 SDA/SCL 及地对电池负极差分, 观察地弹幅度
      ④ 长时间带载试跑积累信心 (事件驱动型失效, 无触发不复现, 不能反向证明)
- [ ] IMU 轴映射正负号实测验证 (倾斜机身观察补偿方向)
- [ ] ★ IMU 功能路线图 (见上文章节): A(重力矢量/校准门控)
  → B(PD阻尼) → C(防翻倒/撞击) → D(坡度/滑移/航向保持/偏航扰动响应)
- [ ] ★ 地形适应设计 (见上文章节): 按 P1~P4 细化并实现
  - P1 寻地式落腿 / P2 悬空检测 / P3 空洞检测 / P4 爬升姿态包络
- [ ] Core1 双核卸载 IK 计算
- [ ] 确认 I2C 总线 0x70 未知设备 (全扫描发现)
- [x] 预留接口的命令与网页控制 (2026-09): 电机 / LED / 蜂鸣器 / 外部 UART /
      外部 I2C+ADC / 14 路空闲 PWM。真机验证了全部命令回显与状态查询; 空闲 PWM
      的 5 秒持久性证明 flush 合并有效 (没被下一次 flush 清零)。见「预留外设」
- [ ] 空闲 PWM 14 路接负载实测 — 值在 RAM 与回显里一致, 但引脚上真实的波形
      没测过 (板子上这些口子都还没接线, 无示波器)
- [ ] 外部 UART0 环回验证: GP0 短接 GP1 后 `!UART0T hello` 应收到 `[U0] hello`
      (当前未短接, 只验证过发送侧回显)
- [ ] 去扭矩归零路径实测: 14 路空闲 PWM 应随 `!S` / 锁定一并归零
      (需先解锁或触发一次电池 FAULT; 代码路径已审, 未实机走一遍)
- [ ] 直流电机正反转 — GP2/GP3 只有 PWM 无方向引脚, 要反转得改板或外接 H 桥方向脚
- [ ] ★ 遥控门与调试页主动控制真机验证 (固件已构建通过, 待烧新 uf2):
      开始页不勾开关 → 连接后 `[RC] locked`、推杆机器不动而 `[CH]` 仍刷新 →
      断开连接 → `unlocked` 且手柄恢复; 服务端心跳停了 6s 后固件自解锁;
      锁定期调试页 `!O 1` + `!F` 仍能走 (`!S` 停); 勾上开关则遥控器照常驱动机器人
- [ ] 运行期频率真机验证: `!CFG loop_ms 5` 回读生效且**走速不变** (只变插值平滑度,
      但 stance_speed / stance_step_mm 的实际行程会变); `!PER0/1` 改周期后 `!PERIPH`
      的 `pwmperiod` 行两板分别变化 → `!SAVE` 断电重启后保持
- [ ] ★ 统一输入层 + 模式页真机验证 (固件已构建通过, 待烧新 uf2):
      ① 切换协议时积分器/按键沿清零 (切回来第一次按键不应误触发);
      ② 同一套 tune/dir/chan 参数对两协议都生效, 遥控页通道面板仍显协议原值 (992 / 128~255);
      ③ 平移方向: 全中性默认要 `!CFG inv_str 1` 才恢复旧手感 (页面遥控页改「方向取反」),
         其余三个方向按实际手感逐个确认;
      ④ 高度: `!CFG height_integrate 0` = 绝对位置 (中位即原高度), 1 = 积分 (回中保持),
         来回切几次确认不跳变; `h_deadzone` 只在积分档生效;
      ⑤ 模式矩阵: 页面上把 `mode_g0` 挂到某个空闲通道 → 保存 → 断电重启仍在;
         解锁改成电平语义后, 开关拨走应立刻上锁;
      ⑥ 组合键: START 单击翻转解锁, ×+↑ 抬腿 (且不会顺带切步态), ○ 急停;
         把某个组合键设成「无」→ 该目标应交给矩阵行 (按键按住 = 生效);
      ⑦ 遥控门 `!RC 0` 锁定时模式暂停; CRSF 侧解锁从边沿变电平是预期行为 (Betaflight 语义)
- [ ] ★ 单击触发 + CRSF 组合键 + 几何页真机验证 (固件已构建通过, 待烧新 uf2):
      ① 先用**改前固件**存一份参数 (`!CFGW`) → 烧新固件上电 → `!CFG` 里 mode_*/combo_*
         的值与之前逐个相同、行为不变 (不升版本这条决策的依据);
      ② 矩阵行勾「单击触发」→ 遥控开关拨一下翻转解锁 (拨回来不复位, 再拨高再翻一次);
         取消勾选恢复"停在区间内才解锁";
      ③ 组合键在遥控上的用法 (遥控上给 CH9 配一个开关):
         `!CFG mode_arm 248` (未分配) → 该目标组合键生效 →
         `!CFG combo_arm 516` (单键 btn 4 = CH9) → CH9 拨高 = 解锁一次;
         改成 `!CFG combo_arm 1540` (加 hold 位) → 拨高期间保持解锁;
      ④ PS2 矩阵行绑按键通道 (验通道极性): `!CFG combo_arm 528` (组合键设「无」) +
         `!CFG mode_arm 92` (通道 11 = PS2 的 D-Pad ←) → 按住 D-Pad ← = 解锁,
         松手 = 上锁 (按下必须是"高"档, 若正相反说明极性又反了);
      ⑤ `!CFG combo_lup 1166` (×+↑ 加 hold 位) → 按住 ×+↑ 每 ~400ms 抬腿一档,
         松开立刻停;
      ⑥ 几何: `!CFG init_height_mm 60` → 重启后站高明显 +10mm;
         `!CFG coxa_angle_rear 1300` → 重启后 RR 基节中位偏移 (5°);
         页面上改任一项 → 提示重启生效, 重启后 `!CFG` 回读是新值
         (这几项测完 `!CFGR` 恢复默认)
- [ ] ★ 校准页 (电压标定 / IMU 重置 / 模式页排版) 真机验证 (固件已构建通过, 待烧新 uf2):
      ① 接上电池 → 校准页「刷新读数」→ 万用表读一次电池电压填进去 → 「按实测标定」:
         「当前分压比」变新值、状态页电压读数 ≈ 万用表, `!BATT` 的换算电压同源一致;
         `!CFGW` 后断电重启仍生效;
      ② 未接电池 (USB 供电) 时标定按钮置灰、点不动; 拔掉电池再插回后读数恢复;
      ③ `!IMUR` 解锁时应被拒 (`[IMUR] Refuse: robot is armed, disarm first (!S)`);
         上锁后执行 → `[IMUR] 已复位并重新初始化` + `=== IMU Status ===`,
         calib 等级回到 0, 平放几秒 sys/gyr 回 3、六面各停一会儿 acc 回 3;
         复位后 Roll/Pitch 短暂无效属正常;
      ④ 模式页排版: 矩阵行与组合键行的「单击触发」在同一列对齐
         (改前组合键行那个勾选框会掉到下一行、矩阵行的会挤出第三列)
- [ ] ★ 版本行 + `!IMU` 传感器行 + 状态总览五张曲线 真机验证 (固件已构建通过, 待烧新 uf2):
      ① `!VER` 应回两行 (`[VER] … (短哈希)` + `[HW] PCB v2`), 开机横幅同款;
      ② `!IMU` 多出 accel/gyro/mag/temp 四行: 静止时加速度模 ≈ 9.81 m/s²
         (即 z ≈ ±981 量级), 翻面各轴跟着变号; 温度 ≈ 室温 (±5°C); 原地转圈 mag 三轴
         有响应。数值不合理先查 UNIT_SEL 与量程 (固件没写过, 默认单位);
      ③ 网页服务端态: 开始页两行版本 + 调参页状态栏「固件 … · 硬件 PCB v2」;
         状态总览五张曲线 1 Hz 增长 (静止时也长, 满一分钟开始滚), 拔掉 IMU 后清空;
      ④ 直连态连一次 → 断开 → 刷新开始页, 两行版本仍在 (localStorage)
- [ ] 外部 UART0 (GP0/GP1) 上位机协议设计 (现为裸文本透明转发, 无帧格式/校验/重传)
- [ ] 外部 I2C (GP26/27 软件位翻转) 接器件读写实测 (固件目前只实现扫描, 板上无器件)
- [ ] 足端传感器接入步态逻辑, 自动进行步态调整

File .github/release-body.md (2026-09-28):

**这一版最大的变化：不装任何东西就能调板子。**

把 Pico 插在你自己电脑上，用 Chrome/Edge 打开
<https://gitcfyang.github.io/hexapod_robot/> → 点「连接」→ 浏览器弹串口选择器选中 Pico，
参数、端口、校准、日志全在网页里改（Web Serial 直接读写 USB 串口，没有本地服务、不经
任何服务器）。不想开网页版也行：下载下面附件里的 `index.html`，双击打开就是同一个页面。

> Safari 不支持 Web Serial，Firefox 需 151+。**烧固件不在网页里** —— 用附件里的 uf2。

固件这边（v0.3.0 以来）：

- **运行时参数**：92 项步态/姿态/几何/遥控/模式/电源/平衡参数用 `!CFG` 或网页在线改，
  `!CFGW` 存 flash 掉电保持（几何组重启后生效）
- **模式页**：解锁/平衡/步态/站姿挂在哪个通道、落在哪几档（模式矩阵），以及一次性动作的
  组合键；遥控器与 PS2 手柄共用同一套，每行可选「单击触发」
- **输入层统一**：CRSF / PS2 常编译，`!MODE` 运行期切换；`!RC` 让网页临时接管遥控，
  失去心跳 6s 自动交还
- **端口页**：复用引脚（UART0 / 输入 UART1 / 电机 / 足端检测 / 外部排针）用途运行期切换，
  状态列报引脚实测电平
- **校准**：逐舵机定机械中心（`!HO`/`!HOS` + 网页面板），电压分压比与 IMU 也能在网页重标
- **外设在线可控**：直流电机 ×2 / 蜂鸣器 / 双 LED / 外部 UART0 / 外部 I2C 或 ADC /
  PCA9685 空闲 14 路 PWM
- **控制周期 50~200Hz、PCA9685 PWM 周期运行期可调**；硬件看门狗、I2C 总线自恢复

工具这边：串口控制台内置 TCP 桥接（多客户端广播、命令反向下发，配 `tools/tcp_monitor.py`
远程操作），网页服务有启停脚本 `tools/webconfig/run.py`（`run.sh` 是它的 Linux 包装）。

附件里的 `hexapod_pico.uf2` 拖进 Pico 的 USB 盘即烧录；PCB/Gerber/BOM/机械 STEP 同在附件里。

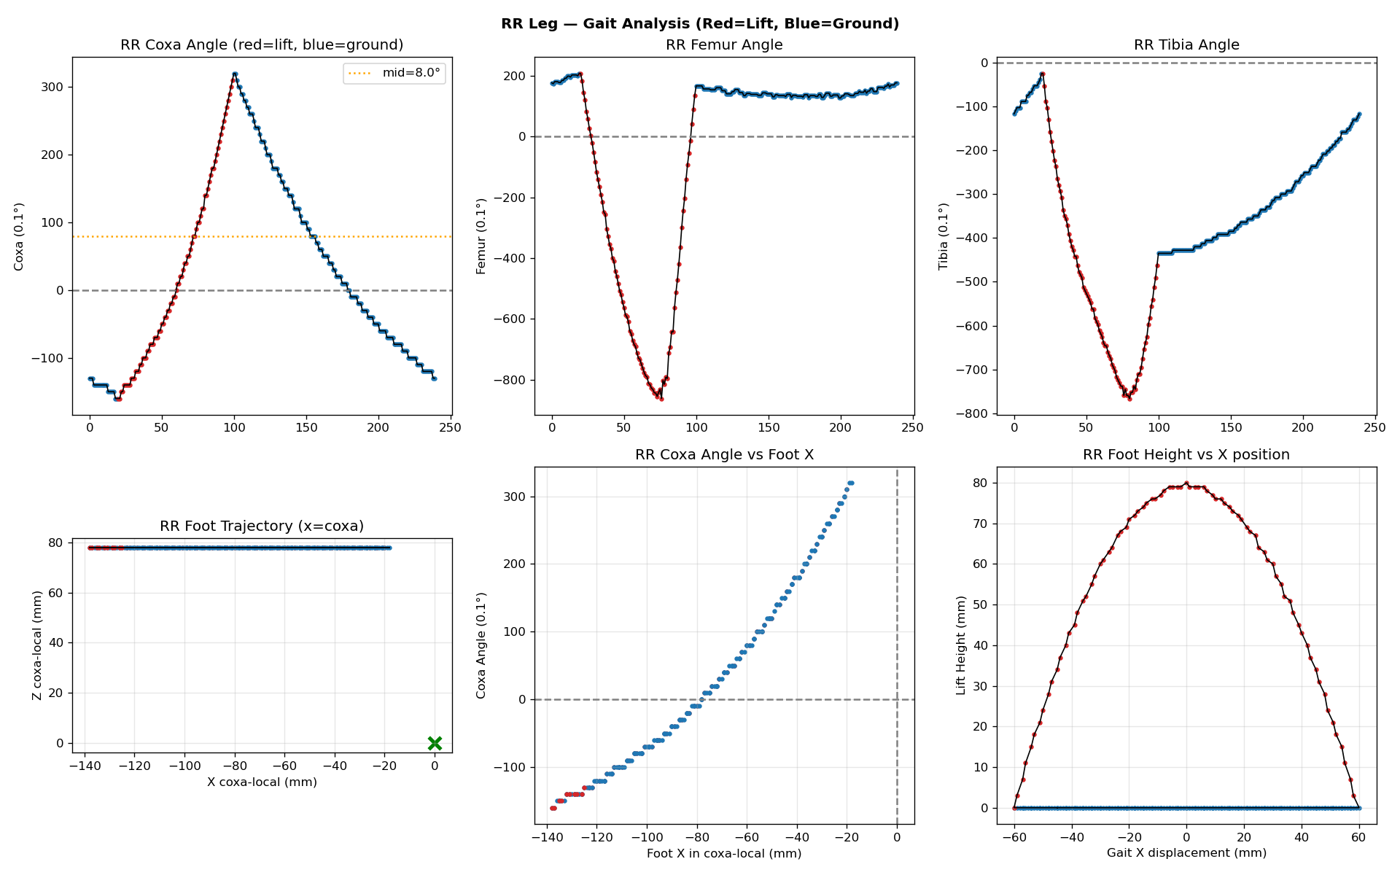
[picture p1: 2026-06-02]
tools/rr_analysis.png

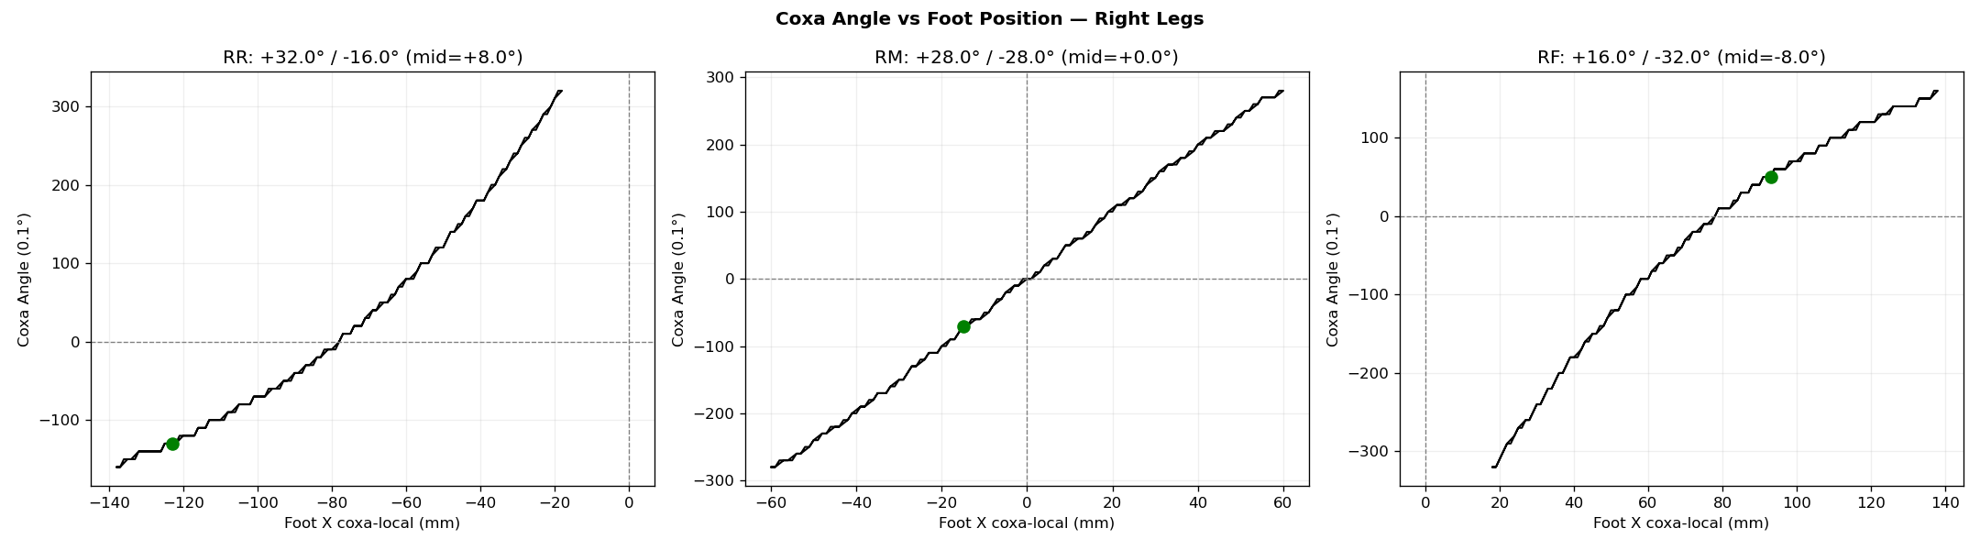
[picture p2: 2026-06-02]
tools/coxa_asymmetry.png

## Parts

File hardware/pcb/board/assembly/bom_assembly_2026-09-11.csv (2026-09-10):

No. | Quantity | Comment | Designator | Footprint | Value | Manufacturer Part | Manufacturer | Supplier Part | Supplier
1 | 6 | 100nF | C1,C2,C3,C4,C5,C6 | C0805 | 100nF | CL21B104KCFNNNE | SAMSUNG(三星) | C28233 | LCSC
2 | 1 | XH2.54*6P_直插 | CN1 | CONN-TH_XH2.54-6P |  | XH2.54*6P_直插 |  | C9900008614 | LCSC
3 | 2 | SMBJ12A | D1,D2 | SMB_L4.6-W3.6-LS5.4-RD |  | SMBJ12A | JJW(捷捷微) | C356757 | LCSC
4 | 1 | SMBJ18A | D3 | SMB_L4.6-W3.6-LS5.4-RD |  | SMBJ18A | JJW(捷捷微) | C356764 | LCSC
5 | 1 | MSK-11027脚 拨动开关 | KEY1 | SW-SMD_MSK-11027 |  | MSK-11027脚 拨动开关 |  | C21381 | LCSC
6 | 1 | 47UH | L1 | IND-SMD_L7.3-W6.6 |  | 47UH |  | C9900023610 | LCSC
7 | 2 | KT-0805Y | LED1,LED2 | LED0805-R-RD |  | KT-0805Y | KENTO | C2296 | LCSC
8 | 2 | KF301-2P接线端子 | P2,P3 | CONN-TH_XY301V-A-5.0-2P |  | KF301-2P接线端子 |  | C9900016950 | LCSC
9 | 3 | S8050 | Q1,Q2,Q3 | SOT-23-3_L2.9-W1.3-P1.90-LS2.4-BR |  | S8050 | Doeshare(德芯) | C2931719 | LCSC
10 | 4 | 10K | R1,R2,R6,R7 | R0805 | 10K | 0805W8F1202T5E | UNI-ROYAL(厚声) |  | LCSC
11 | 2 | 4.7K | R3,R4 | R0805 | 4.7K | 0805W8F1202T5E | UNI-ROYAL(厚声) |  | LCSC
12 | 4 | 1K | R5,R8,R9,R11 | R0805 | 1K | 0805W8F1202T5E | UNI-ROYAL(厚声) |  | LCSC
13 | 3 | 220 | R10,R12,R13 | R0805 | 220 | 0805W8F1202T5E | UNI-ROYAL(厚声) |  | LCSC
14 | 1 | 330K | R14 | R0805 | 330K | 0805W8F1202T5E | UNI-ROYAL(厚声) |  | LCSC
15 | 1 | 47K | R15 | R0805 | 47K | 0805W8F1202T5E | UNI-ROYAL(厚声) |  | LCSC
16 | 1 | 10 | R16 | R0805 | 10 | 0805W8F1202T5E | UNI-ROYAL(厚声) |  | LCSC
17 | 2 | 100 | R17,R18 | R0805 | 100 | 0805W8F1202T5E | UNI-ROYAL(厚声) |  | LCSC
18 | 2 | PCA9685PW,112 | U1,U2 | TSSOP-28_L9.7-W4.4-P0.65-LS6.4-BL |  | PCA9685PW,112 | NXP(恩智浦) | C2688894 | LCSC
19 | 8 | HX PZ2.54-3x4P ZZ | U4,U5,U6,U7,U8,U9,U10,U11 | HDR-TH_12P-P2.54-V-M-R3-C4-S2.54 |  | HX PZ2.54-3x4P ZZ | hanxia(韩下) | C32713291 | LCSC
20 | 1 | JXT-PM2.54-1X8P-A9 | U12 | HDR-TH_8P-P2.54-V-F_ESW-108-44-G-D |  | JXT-PM2.54-1X8P-A9 | JXTCONN(聚兴泰) | C54803361 | LCSC
21 | 1 | LM2596S-5.0/TR | U15 | TO-263-5_L10.1-W8.7-P1.70-LS15.2-BR |  | LM2596S-5.0/TR |  | C516006 | LCSC
22 | 1 | XT60PB-M | U16 | CONN-TH_XT60PB-M |  | XT60PB-M |  | C9900017179 | LCSC
23 | 2 | 220uF | U17,U28 | CAP-SMD_BD6.3-L6.6-W6.6-LS7.2-FD |  | 220uF |  | C2941234 | LCSC
24 | 1 | CUI_CST-931AP | U21 | BUZ-TH_BD9.0-P4.00-D0.6-L-FD |  | CUI_CST-931AP |  | C9900006511 | LCSC
25 | 1 | PICO | U23 | COMM-SMD_L51.0-W21.0-P2.54_SC0916 |  | PICO | Raspberry Pi(树莓派) | C7203002 | LCSC
26 | 2 | AO4407A | U24,U25 | SOP-8_L4.9-W3.9-P1.27-LS6.0-BL |  | AO4407A |  | C3019374 | LCSC
27 | 1 | SS14 | U26 | SOD-323_L1.7-W1.3-LS2.5-RD |  | SS14 |  | C9900017063 | LCSC
28 | 1 | 7位插座 | U29 | HDR-TH_7P-P2.54-V-F |  | 7位插座 |  | C9900023763 | LCSC
29 | 1 | BUTTON | U31 | SW-SMD_L3.9-W2.9-LS4.9-L |  | BUTTON |  | C9900015607 | LCSC

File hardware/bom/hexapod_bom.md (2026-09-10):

# 全项目物料清单 (BOM)

| 类别 | 细分 | 数量 | 单价 | 总价 | 链接 | 备注 |
|---|---|---|---|---|---|---|
| 主体硬件 | 机器人框架 | 1 | 237 | 237 | [🔗](https://item.taobao.com/item.htm?id=656344915867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) | |
| | 舵机 | 18 | 38 | 684 | [🔗](https://item.taobao.com/item.htm?id=809724337214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) | |
| PCB | pcb本体 | 1 | 0 | 0 | [🔗](https://www.jlc.com/newOrder/) | |
| | XT60M | 1 | 1.85 | 1.85 | [🔗](https://item.taobao.com/item.htm?id=599294573848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) | U16 |
| | 开关（两档） | 1 | 2.64 | 2.64 | [🔗](https://item.taobao.com/item.htm?id=557092773462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) | KEY1 |
| | 0630 47uH | 1 | 0.35 | 0.35 | [🔗](https://item.taobao.com/item.htm?id=528379639825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) | L1 |
| | 220uF 10V | 2 | 0.17 | 0.34 | [🔗](https://item.taobao.com/item.htm?id=522554867387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) | U17,U28 |
| | S8050 | 1 | 1.32 | 1.32 | [🔗](https://item.taobao.com/item.htm?id=522577964105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) | Q1,Q2,Q3 |
| | 0805 蓝LED，红LED | 2 | 0.82 | 1.64 | [🔗](https://item.taobao.com/item.htm?id=522554271548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) | LED1,LED2 |
| | SMBJ12A | 1 | 3 | 3 | [🔗](https://item.taobao.com/item.htm?id=565061559708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) | D1,D2,D3 |
| | KF301 2P | 2 | 0.3 | 0.6 | [🔗](https://item.taobao.com/item.htm?id=554756924317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) | P2,P3 |
| | 2.54 1*7P | 1 | 1.21 | 1.21 | [🔗](https://item.taobao.com/item.htm?id=522579376259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) | U29 |
| | XH2.54 6P | 1 | 0.66 | 0.66 | [🔗](https://item.taobao.com/item.htm?id=522555535449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) | CN1 |
| | 0805 100nF | 1 | 2.75 | 2.75 | [🔗](https://item.taobao.com/item.htm?id=522576552845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) | C1,C2,C3,C4,C5,C6 |
| | PCA9685PW | 2 | 13.2 | 26.4 | [🔗](https://item.taobao.com/item.htm?id=739632309278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) | U1,U2 |
| | PICO（不焊接） | 1 | 9.75 | 9.75 | [🔗](https://item.taobao.com/item.htm?id=846281337137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) | U23 |
| | 3*4P 2.54 | 1 | 4.3 | 4.3 | [🔗](https://detail.tmall.com/item.htm?id=716488035763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) | U4,U5,U6,U7,U8,U9,U10,U11 |
| | BNO055（不焊接) | 1 | 45 | 45 | [🔗](https://item.taobao.com/item.htm?id=950978830003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) | U12 |
| | AO4407A | 2 | 0.91 | 1.82 | [🔗](https://item.taobao.com/item.htm?id=619612296393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) | U24,U25 |
| | 3*4 贴片2脚 按钮 | 1 | 1.98 | 1.98 | [🔗](https://item.taobao.com/item.htm?id=556985020016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) | U31 |
| | SS14 1N5819 | 1 | 1.65 | 1.65 | [🔗](https://item.taobao.com/item.htm?id=522574162326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) | U26 |
| | 蜂鸣器 | 1 | 0.44 | 0.44 | [🔗](https://item.taobao.com/item.htm?id=626390462344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) | U21 |
| | LM2596S-5.0 | 1 | 5.7 | 5.7 | [🔗](https://item.taobao.com/item.htm?id=522577612783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) | U15 |
| | 0805 10K | 1 | 3.3 | 3.3 | [🔗](https://item.taobao.com/item.htm?id=522573121620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) | R1,R2,R6,R7 |
| | 0805 4.7K | 1 | 3.3 | 3.3 | 同上 | R3,R4 |
| | 0805 1K | 1 | 3.3 | 3.3 | 同上 | R5,R8,R9,R11 |
| | 0805 220 | 1 | 3.3 | 3.3 | 同上 | R10,R12,R13 |
| | 0805 330K | 1 | 3.3 | 3.3 | 同上 | R14 |
| | 0805 47K | 1 | 3.3 | 3.3 | 同上 | R15 |
| | 0805 10 | 1 | 3.3 | 3.3 | 同上 | R16 |
| | 0805 100 | 1 | 3.3 | 3.3 | 同上 | R17,R18 |
| 遥控器及接收机 | PS2手柄套装 | 1 | 34.3 | 34.3 | [🔗](https://item.taobao.com/item.htm?id=37682179963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) | 手柄+横插转接板XH2.54 |
| 电池及充电器 | 2S2P 18650（田字） | 1 | 36.3 | 36.3 | [🔗](https://item.taobao.com/item.htm?id=977585184389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) | |
| | 充电器 | 1 | 7.8 | 7.8 | [🔗](https://item.taobao.com/item.htm?id=890594688764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) | |
| 其他 | xh2.54 6P 连接线 | 1 | 7.2 | 7.2 | [🔗](https://item.taobao.com/item.htm?id=745033904148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) | 双头同向 |
| | 舵机延长线 | 6 | 0.7 | 4.199999999999999 | [🔗](https://item.taobao.com/item.htm?id=524828403744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) | 60芯棕红橙 |
| | 3m双面胶带（粘电路板） | 1 | | 0 | | |
| | 扎带（整理线材） | 1 | | 0 | | |
| 合计 | | | | 1150.6 | | |

> 由 `tools/xlsx_bom_to_csv.py` 从 xlsx 生成 (xlsx 为本地编辑源, 不入库)。
> 修改物料: 直接编辑 csv 的链接列 (URL 文本), 或保留本地 xlsx 重新生成。

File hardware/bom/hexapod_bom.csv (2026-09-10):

类别 | 细分 | 数量 | 单价 | 总价 | 链接 | 备注
主体硬件 | 机器人框架 | 1 | 237 | 237 | https://item.taobao.com/item.htm?id=656344915867
 | 舵机 | 18 | 38 | 684 | https://item.taobao.com/item.htm?id=809724337214&skuId=5497575776978
PCB | pcb本体 | 1 | 0 | 0 | https://www.jlc.com/newOrder/
 | XT60M | 1 | 1.85 | 1.85 | https://item.taobao.com/item.htm?id=599294573848&skuId=4184175637803 | U16
 | 开关（两档） | 1 | 2.64 | 2.64 | https://item.taobao.com/item.htm?id=557092773462&skuId=5013085902613 | KEY1
 | 0630 47uH | 1 | 0.35 | 0.35 | https://item.taobao.com/item.htm?id=528379639825 | L1
 | 220uF 10V | 2 | 0.17 | 0.34 | https://item.taobao.com/item.htm?id=522554867387&skuId=5898653519716 | U17,U28
 | S8050 | 1 | 1.32 | 1.32 | https://item.taobao.com/item.htm?id=522577964105 | Q1,Q2,Q3
 | 0805 蓝LED，红LED | 2 | 0.82 | 1.64 | https://item.taobao.com/item.htm?id=522554271548&skuId=5766142345198 | LED1,LED2
 | SMBJ12A | 1 | 3 | 3 | https://item.taobao.com/item.htm?id=565061559708 | D1,D2,D3
 | KF301 2P | 2 | 0.3 | 0.6 | https://item.taobao.com/item.htm?id=554756924317&skuId=5775816901623 | P2,P3
 | 2.54 1*7P | 1 | 1.21 | 1.21 | https://item.taobao.com/item.htm?id=522579376259 | U29
 | XH2.54 6P | 1 | 0.66 | 0.66 | https://item.taobao.com/item.htm?id=522555535449 | CN1
 | 0805 100nF | 1 | 2.75 | 2.75 | https://item.taobao.com/item.htm?id=522576552845 | C1,C2,C3,C4,C5,C6
 | PCA9685PW | 2 | 13.2 | 26.4 | https://item.taobao.com/item.htm?id=739632309278 | U1,U2
 | PICO（不焊接） | 1 | 9.75 | 9.75 | https://item.taobao.com/item.htm?id=846281337137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 | U23
 | 3*4P 2.54 | 1 | 4.3 | 4.3 | https://detail.tmall.com/item.htm?id=716488035763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 | U4,U5,U6,U7,U8,U9,U10,U11
 | BNO055（不焊接) | 1 | 45 | 45 | https://item.taobao.com/item.htm?ali_trackid=318_f91c7c0e1e2c1b2d942ca85080b62ec8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 | U12
 | AO4407A | 2 | 0.91 | 1.82 | https://item.taobao.com/item.htm?id=619612296393 | U24,U25
 | 3*4 贴片2脚 按钮 | 1 | 1.98 | 1.98 | https://item.taobao.com/item.htm?id=556985020016&skuId=6133111010350 | U31
 | SS14 1N5819 | 1 | 1.65 | 1.65 | https://item.taobao.com/item.htm?id=522574162326 | U26
 | 蜂鸣器 | 1 | 0.44 | 0.44 | https://item.taobao.com/item.htm?id=626390462344 | U21
 | LM2596S-5.0 | 1 | 5.7 | 5.7 | https://item.taobao.com/item.htm?id=522577612783 | U15
 | 0805 10K | 1 | 3.3 | 3.3 | https://item.taobao.com/item.htm?id=522573121620&sku_properties=-1%3A-1%3B-2%3A-2 | R1,R2,R6,R7
 | 0805 4.7K | 1 | 3.3 | 3.3 | 同上 | R3,R4
 | 0805 1K | 1 | 3.3 | 3.3 | 同上 | R5,R8,R9,R11
 | 0805 220 | 1 | 3.3 | 3.3 | 同上 | R10,R12,R13
 | 0805 330K | 1 | 3.3 | 3.3 | 同上 | R14
 | 0805 47K | 1 | 3.3 | 3.3 | 同上 | R15
 | 0805 10 | 1 | 3.3 | 3.3 | 同上 | R16
 | 0805 100 | 1 | 3.3 | 3.3 | 同上 | R17,R18
遥控器及接收机 | PS2手柄套装 | 1 | 34.3 | 34.3 | https://item.taobao.com/item.htm?id=37682179963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 | 手柄+横插转接板XH2.54
电池及充电器 | 2S2P 18650（田字） | 1 | 36.3 | 36.3 | https://item.taobao.com/item.htm?id=977585184389&skuId=6229581439320
 | 充电器 | 1 | 7.8 | 7.8 | https://item.taobao.com/item.htm?id=890594688764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
其他 | xh2.54 6P 连接线 | 1 | 7.2 | 7.2 | https://item.taobao.com/item.htm?id=745033904148&skuId=5142104993864 | 双头同向
 | 舵机延长线 | 6 | 0.7 | 4.199999999999999 | https://item.taobao.com/item.htm?id=524828403744&skuId=3515483316006 | 60芯棕红橙
 | 3m双面胶带（粘电路板） | 1 |  | 0
 | 扎带（整理线材） | 1 |  | 0
合计 |  |  |  | 1150.6

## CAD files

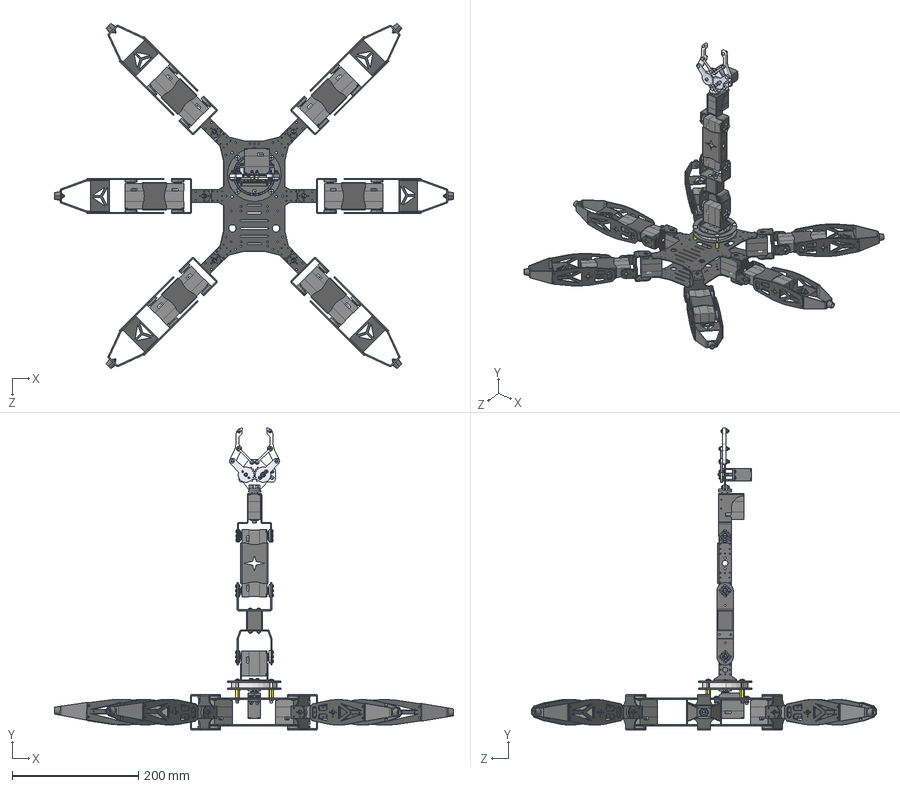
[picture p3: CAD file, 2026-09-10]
hardware/mechanical/hexapod.step
633.3 x 479.1 x 548.2 mm
Lm2奻狟啣 x 3
十字大u支架 x 6
小u连接件 x 6
总线双轴舵机 x 18
ﾋﾜﾁﾏｴﾓｶ貲ﾌ x 18
塑料主舵盘 x 18
腿部支架 x 12
脚部支架 x 6
褐菜 x 6
cross recessed pan head screws gb_GB_CROSS_SCREWS_TYPE1 M3X10-10 H type-S x 6
hex nuts, style 1-grades ab gb_GB_FASTENER_NUT_SNAB1 M3-S x 6
蚾庉璃 x 6
总线单轴舵机 x 2
GB818-M4X10-4.8 x 4
GB6170-M4-ZN-10 x 8
Lm2苤埴攫 x 2
金属主舵盘1 x 6
cross recessed pan head screws gb_GB_CROSS_SCREWS_TYPE1 M3X5-5 Z type-N x 35
deep groove ball bearings g_Rolling bearings 6811 GB 276-94
长窄u支架
GB818-M3X8-ZN-4.8 x 8
GB6170-M3-ZN-10 x 12
Lm2苤埴遠 x 2
GB818-M4X35 x 4
M4X14双通铜柱 x 4
GB818-M3X18-ZN-4.8 x 4
总线双轴舵机1 x 4
金属从舵盘 x 3
湮u1
长方体连接
笢u
cross recessed pan head screws gb_GB_CROSS_SCREWS_TYPE1 M3X38-38 H type-N x 4
中长小u连接件
錨璃3
____ ______.STEP
______.STEP x 2
______-0.STEP x 3
________ 2.STEP
________.STEP
______-1.STEP x 2
____.STEP x 2
____-2.STEP x 4
GB818-M3X10-ZN-4.8.STEP x 4
GB6170-M3________.STEP x 11
GB818-M3X14-ZN-4.8.STEP x 6
GB818-M3X12-ZN-4.8.STEP
GB818-M3X6-ZN-4.8.STEP x 4

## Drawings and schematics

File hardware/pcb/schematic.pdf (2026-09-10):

降压

# 舵机驱动

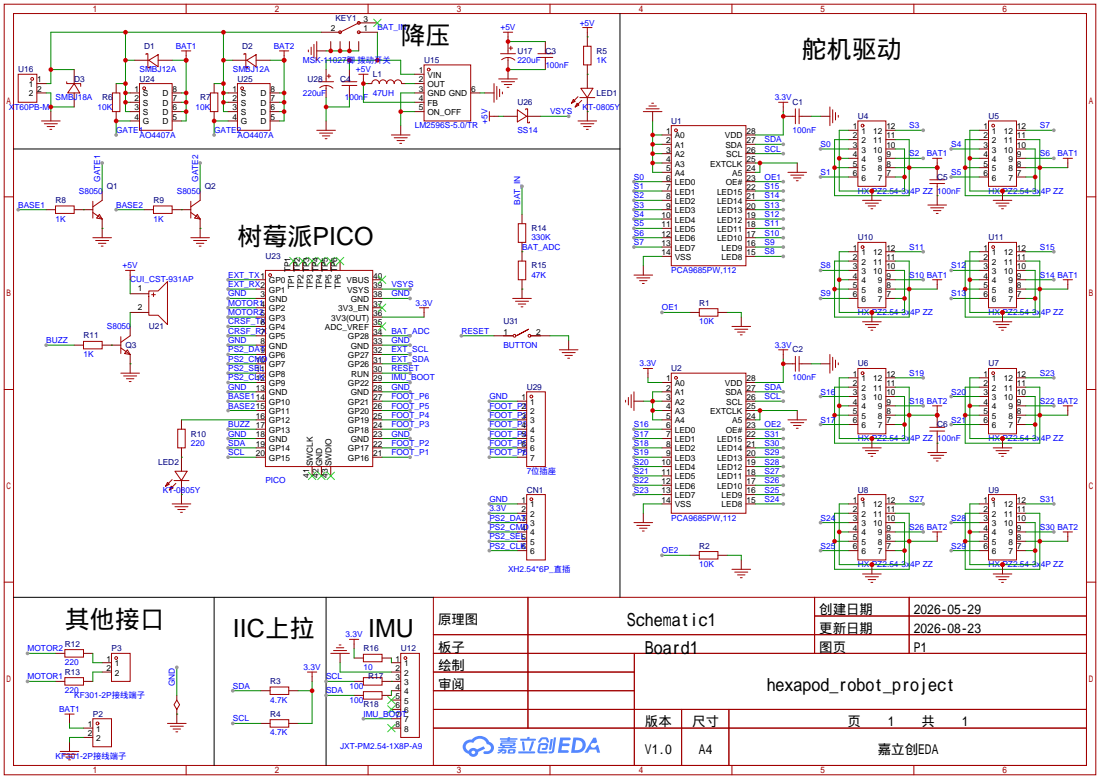
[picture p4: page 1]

更新日期 | 2026-08-23

板子 | Board1 | 图页 | P1

V1.0 | A4 | 嘉立创EDA

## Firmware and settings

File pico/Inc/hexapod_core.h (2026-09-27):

/**
 * @file hexapod_core.h
 * @brief 六足机器人核心控制模块
 * @note 主要控制循环和状态管理
 */

#ifndef HEXAPOD_CORE_H
#define HEXAPOD_CORE_H

#include "hexapod_types.h"
#include "hexapod_hal.h"
#include "hexapod_ik.h"
#include "hexapod_gait.h"

/* ==================== 配置参数 ==================== */

#define DEFAULT_GAIT_SPEED      100     // 默认步态速度
#define DEFAULT_LEG_LIFT_HEIGHT 40      // 默认抬腿高度（mm）(站立深度 INIT_Y=50mm 的 80%)
/* CONTROL_LOOP_PERIOD_MS 已迁至 hexapod_config.h —— 它是运行时可调参数
 * (loop_ms), 宏指向 g_params, 需要 config.h 的参数实体声明。 */
#define GAIT_STEP_PERIOD_MS     60       // 步态推进周期（ms）。越大=越慢。RIPPLE_12有12步，
                                         // 60ms×12=720ms/周期。步长80mm时速度=80/0.72≈111mm/s。

/* ==================== 机器人实例 ==================== */

typedef struct hexapod {                        // tag: HAL 侧要前置声明这个类型
    control_state_t  state;                     // 控制状态
    leg_config_t     leg_configs[CNT_LEGS];     // 腿部配置
    bool             initialized;               // 初始化标志
    bool             servos_enabled;            // 舵机使能标志
    uint32_t         last_update_time;          // 上次舵机刷新时间
    uint32_t         last_gait_time;            // 上次步态推进时间
} hexapod_t;

/* ==================== 核心功能 ==================== */

/**
 * @brief 初始化六足机器人
 * @param robot 机器人实例
 * @param configs 腿部配置数组（6个腿）
 * @return true表示成功
 */
bool hexapod_init(hexapod_t *robot, const leg_config_t *configs);

/**
 * @brief 主控制循环（应在定时器中调用）
 * @param robot 机器人实例
 */
void hexapod_update(hexapod_t *robot);

/**
 * @brief 使能/禁用舵机
 * @param robot 机器人实例
 * @param enable true表示使能
 */
void hexapod_enable_servos(hexapod_t *robot, bool enable);

/**
 * @brief 设置机身位置
 * @param robot 机器人实例
 * @param pos 位置坐标
 */
void hexapod_set_body_position(hexapod_t *robot, const coord3d_t *pos);

/**
 * @brief 设置机身旋转
 * @param robot 机器人实例
 * @param rot 旋转角度（X-横滚, Y-航向, Z-俯仰）
 */
void hexapod_set_body_rotation(hexapod_t *robot, const coord3d_t *rot);

/**
 * @brief 设置行走参数
 * @param robot 机器人实例
 * @param travel 行走距离和旋转（X-前后, Z-左右, Y-旋转）
 */
void hexapod_set_travel(hexapod_t *robot, const coord3d_t *travel);

/**
 * @brief 设置抬腿高度
 * @param robot 机器人实例
 * @param height 高度（mm）
 */
void hexapod_set_leg_lift_height(hexapod_t *robot, int16_t height);

/**
 * @brief 设置步态类型
 * @param robot 机器人实例
 * @param gait_type 步态类型
 */
void hexapod_set_gait(hexapod_t *robot, gait_type_t gait_type);

/**
 * @brief 设置平衡模式
 * @param robot 机器人实例
 * @param enable true表示启用平衡
 */
void hexapod_set_balance_mode(hexapod_t *robot, bool enable);

/**
 * @brief 紧急停止
 * @param robot 机器人实例
 */
void hexapod_emergency_stop(hexapod_t *robot);

/**
 * @brief 获取当前状态
 * @param robot 机器人实例
 * @return 控制状态指针
 */
const control_state_t* hexapod_get_state(const hexapod_t *robot);

/**
 * @brief 获取最近一次 IK 解算结果（调试用）
 * @param robot 机器人实例
 * @param leg_index 腿索引 (0-5)
 * @return IK 角度，robot 为空时返回 NULL
 */
const ik_solution_t* hexapod_get_last_ik(const hexapod_t *robot, leg_index_t leg_index);

/**
 * @brief 执行单步（调试用）
 * @param robot 机器人实例
 */
void hexapod_single_step(hexapod_t *robot);

/* ==================== 辅助功能 ==================== */

/**
 * @brief 获取腿部XZ平面长度
 * @param robot 机器人实例
 * @return XZ平面长度
 */
uint16_t hexapod_get_legs_xz_length(const hexapod_t *robot);

/**
 * @brief 调整腿部位置到指定长度
 * @param robot 机器人实例
 * @param xz_length 目标XZ长度
 */
void hexapod_adjust_leg_positions(hexapod_t *robot, uint16_t xz_length);

/**
 * @brief 逐周期插值缩放站立位置 (XZ 平面)
 *        向 stance_mode 目标平滑过渡，避免足端擦地。
 *        stance_mode: -1=窄(80%), 0=正常(100%), +1=宽(120%)
 * @param robot 机器人实例
 */
void hexapod_apply_stance(hexapod_t *robot);

/**
 * @brief 重置腿部初始角度
 * @param robot 机器人实例
 */
void hexapod_reset_leg_init_angles(hexapod_t *robot);

/**
 * @brief 旋转腿部初始角度
 * @param robot 机器人实例
 * @param delta_angle 旋转角度增量（0.1度）
 */
void hexapod_rotate_leg_init_angles(hexapod_t *robot, int16_t delta_angle);

#endif /* HEXAPOD_CORE_H */

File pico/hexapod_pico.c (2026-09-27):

/**
 * @file main_pico.c
 * @brief Raspberry Pi Pico六足机器人主程序
 * @note 使用Pico SDK编译，支持CRSF接收器(ELRS)和串口命令双输入模式
 *
 * 调试流水线（通过 DEBUG_LEVEL 控制，USB CDC 串口输出）：
 *   Level 1:  接收器 → 原始通道值
 *   Level 2:  通道值  → 运动控制量 (travel/gait/lift)
 *   Level 3:  控制量  → 舵机角度 (每腿 coxa/femur/tibia)
 *
 * 运行时命令（串口 115200 baud）：
 *   !V         切换调试等级 (0→1→2→3→0)
 *   !I         打印 CRSF 链路信息和 8 通道原始值
 *   !A         打印 18 路舵机角度/脉宽快照
 */

#include "pico/stdlib.h"
#include "pico/time.h"
#include "hardware/watchdog.h"
#include "hexapod_core.h"
#include "hexapod_config.h"
#include "hexapod_crsf.h"
#include "hexapod_i2c_protocol.h"
#include "hexapod_hal.h"
#include "hexapod_store.h"

/* 全局机器人实例 */
static hexapod_t g_robot;

/**
 * @brief 机器人初始化
 */
bool robot_init(void)
{
    leg_config_t leg_configs[CNT_LEGS];
    hexapod_get_default_config(leg_configs);

    if (!hexapod_init(&g_robot, leg_configs)) {
        hal_debug_printf("Robot init failed!\r\n");
        return false;
    }

    hexapod_set_leg_lift_height(&g_robot, DEFAULT_LEG_LIFT_HEIGHT);
    hexapod_set_gait(&g_robot, GAIT_TRIPOD_6);   /* 三角步态=六足标准行走; RIPPLE 波浪式逐腿摆动观感如蠕动, 仅作 !G0 备选 */

    hal_debug_printf("Robot initialized successfully!\r\n");
    return true;
}

/* ==================== 调试辅助函数 ==================== */

/**
 * @brief Level 1 调试：打印 CRSF 链接状态 + 8 通道原始值
 *
 * 预期值参考（CRSF 协议）：
 *   CH1~CH8 范围 172~1811，中位 992
 *   摇杆居中 → ~992，推到底 → ~172 或 ~1811
 *   拨杆低位 → <792，中位 → ~992，高位 → >1192
 */
static void debug_print_crsf(const crsf_state_t *crsf)
{
    if (!crsf) {
        hal_debug_printf("[DBG1] CRSF state unavailable\r\n");
        return;
    }

    hal_debug_printf("[DBG1] Link:%s Frames:%lu Age:%lums\r\n",
                crsf->link_connected ? "OK" : "NO",
                crsf->frame_count,
                hal_get_tick_ms() - crsf->last_frame_time_ms);

    hal_debug_printf("[DBG1] CH1(Str/Rol):%u CH2(Fwd/Pit):%u CH3(Hgt/Hgt):%u CH4(Trn/Yaw):%u "
                "CH5(Arm):%u CH6(Gait):%u CH7(Spd):%u CH8(Bal):%u\r\n",
                crsf->channels[0], crsf->channels[1],
                crsf->channels[2], crsf->channels[3],
                crsf->channels[4], crsf->channels[5],
                crsf->channels[6], crsf->channels[7]);
}

/**
 * @brief Level 2 调试：打印通道→控制量映射结果
 *
 * 预期值参考：
 *   robot_on:   CH5 高位→1 (解锁), 低位→0 (锁定)
 *   travel.x:   摇杆前推→+50, 后拉→-50
 *   travel.z:   摇杆右推→-40, 左推→+40 (取反)
 *   travel.y:   摇杆右转→+50, 左转→-50
 *   gait_type:  CH6 低位→0(RIPPLE), 中位→1(TRIPOD), 高位→3(WAVE)
 */
static void debug_print_control(const control_state_t *s)
{
    hal_debug_printf("[DBG2] ON:%d Bal:%d Travel(X:%d Y:%d Z:%d) Gait:%d Lift:%d\r\n",
                s->robot_on, s->balance_mode,
                s->travel_length.x, s->travel_length.y, s->travel_length.z,
                s->gait_type, s->leg_lift_height);
    hal_debug_printf("[DBG2] BodyPos Y:%d  BodyRot(P:%d Y:%d R:%d)\r\n",
                s->body_pos.y,
                s->body_rot.x, s->body_rot.y, s->body_rot.z);
}

/**
 * @brief Level 3 调试：打印每腿 IK 解算角度
 */
static void debug_print_ik_angles(void)
{
    static const char* leg_name[CNT_LEGS] = {"RR","RM","RF","LR","LM","LF"};
    hal_debug_printf("[DBG3] IK angles (Cox/Fem/Tib, 0.1deg):\r\n");
    for (uint8_t i = 0; i < CNT_LEGS; i++) {
        const ik_solution_t *ik = hexapod_get_last_ik(&g_robot, (leg_index_t)i);
        if (ik) {
            hal_debug_printf("  %s: %d %d %d %s%s\r\n",
                        leg_name[i],
                        ik->coxa_angle, ik->femur_angle, ik->tibia_angle,
                        ik->solution_error ? "ERR " : "",
                        ik->solution_warning ? "WARN" : "");
        }
    }
    uint8_t cnt = hal_debug_get_last_servo_count();
    hal_debug_printf("[DBG3] Servos flushed: %u/%u\r\n", cnt,
                pca9685_get_board_count() * 9);
}

/* ==================== 主函数 ==================== */

/**
 * @brief 主函数
 */
int main(void)
{
    stdio_init_all();
    sleep_ms(2000);  /* 等待USB串口稳定 */

    hal_debug_printf("\r\n=================================\r\n");
    hal_debug_printf("Hexapod Robot - Raspberry Pi Pico\r\n");
    hal_debug_printf("=================================\r\n");
    hal_fw_version_print();     /* 网页开始页/串口都靠这行核对板上固件 */

    /* 非易失存储初始化: 扫描日志环头 + 记录 BOOT 事件
     * (此阶段看门狗尚未启用, flash 写安全) */
    store_init();

    /* 运行时参数: 先填默认值, 再用 flash 记录覆盖。
     * ★ 必须在 robot_init() 之前 —— 步长/阈值/开关都在初始化流程里被读。 */
    params_init();
    params_load();

    /* ==================== 上电电池检测 (先于舵机供电) ====================
     *
     * 安全设计:
     *   1. 舵机供电引脚 (GP10/GP11) 默认断电
     *   2. 先读电池电压:
     *      > 8.8V: 过压, 拒绝启动 (红灯 + 蜂鸣), 每 5s 复查
     *      < 6.6V: 过放, 拒绝启动 (红灯 + 蜂鸣), 每 5s 复查
     *   3. 电压在安全窗口 → 开启舵机供电 → 初始化舵机
     *   4. 防止过压烧舵机 + 过放伤电池 + 低压舵机抖动
     */
    hal_servo_power_init();  /* 初始化供电引脚, 保持断电状态 */

    /* batt_check 是运行时参数, 故这里用运行时分支而非 #if。
     * 两个等待循环里都能用 !CFG 改阈值, 或直接 !CFG batt_check 0 放弃检测
     * 继续启动 —— 分压电路还没验证时这是唯一的逃生口。 */
    if (BATTERY_CHECK_ENABLED) {
        uint16_t boot_voltage = hal_get_battery_voltage();
        hal_debug_printf("Battery: %u mV\r\n", boot_voltage);

        if (boot_voltage > BATTERY_OVERVOLTAGE_MV) {
            /* 电压过高: 拒绝启动, 红色 LED 常亮 + 蜂鸣报警
             * 可能原因: 误接 3S 电池 / 电源故障 / 分压电阻焊接错误 */
            hal_debug_printf("BATTERY OVERVOLTAGE (%u mV > %u mV)! Servo power DISABLED.\r\n",
                             boot_voltage, BATTERY_OVERVOLTAGE_MV);
            store_log_event(STORE_EVT_BATT_OV, boot_voltage);
            hal_led_set(1, true);  /* 红色 LED 常亮 */
            uint16_t ov_alarm_notes[] = {1200, 0, 1200, 0, 1200};
            uint16_t ov_alarm_dur[]   = {200, 100, 200, 100, 400};
            hal_play_sound(5, ov_alarm_notes, ov_alarm_dur);

            while (1) {
                /* 每 5s 复查电压, 降到阈值以下后自动继续启动
                 * 分 50 次轮询, 保持 !I2C 等 USB 诊断命令可用 */
                for (int i = 0; i < 50; i++) {
                    hal_poll_usb_commands(NULL);
                    sleep_ms(100);
                }
                boot_voltage = hal_get_battery_voltage();
                if (!BATTERY_CHECK_ENABLED) {
                    hal_led_set(1, false);
                    hal_debug_printf("Battery check disabled at runtime, continuing boot...\r\n");
                    break;
                }
                if (boot_voltage <= BATTERY_OVERVOLTAGE_MV) {
                    hal_led_set(1, false);
                    hal_debug_printf("Battery recovered: %u mV, continuing boot...\r\n",
                                     boot_voltage);
                    break;
                }
                /* 仍在过压: 周期性蜂鸣提醒 */
                hal_play_sound(5, ov_alarm_notes, ov_alarm_dur);
            }
        } else if (boot_voltage < BATTERY_CUTOFF_MV) {
            /* 电压过低: 拒绝启动, 红色 LED 常亮 + 蜂鸣报警 */
            hal_debug_printf("BATTERY TOO LOW (%u mV < %u mV)! Servo power DISABLED.\r\n",
                             boot_voltage, BATTERY_CUTOFF_MV);
            store_log_event(STORE_EVT_BATT_CUTOFF, boot_voltage);
            hal_led_set(1, true);  /* 红色 LED 常亮 */
            uint16_t alarm_notes[] = {200, 0, 200, 0, 200};
            uint16_t alarm_dur[]   = {200, 100, 200, 100, 400};
            hal_play_sound(5, alarm_notes, alarm_dur);

            while (1) {
                /* 等待换电池/充电, 每 5s 复查一次电压, 恢复后自动继续
                 * 分 50 次轮询, 保持 !I2C 等 USB 诊断命令可用 */
                for (int i = 0; i < 50; i++) {
                    hal_poll_usb_commands(NULL);
                    sleep_ms(100);
                }
                boot_voltage = hal_get_battery_voltage();
                if (!BATTERY_CHECK_ENABLED) {
                    hal_led_set(1, false);
                    hal_debug_printf("Battery check disabled at runtime, continuing boot...\r\n");
                    break;
                }
                if (boot_voltage >= BATTERY_RECOVERY_MV) {
                    hal_led_set(1, false);
                    hal_debug_printf("Battery recovered: %u mV, continuing boot...\r\n",
                                     boot_voltage);
                    break;
                }
            }
        } else if (boot_voltage < BATTERY_WARNING_MV) {
            /* 低压警告: 允许启动但红灯闪烁提醒 */
            hal_debug_printf("BATTERY LOW (%u mV)! Charge soon.\r\n", boot_voltage);
            store_log_event(STORE_EVT_BATT_WARN, boot_voltage);
        }
    } else {
        /* 电池检测已禁用: 跳过 ADC 读取 */
        hal_debug_printf("Battery check DISABLED (batt_check=0)\r\n");
    }

    /* 电池检测通过 → 正式开机。
     * 注意: 舵机供电 (GP10/GP11) 保持断电, 由 ARM 解锁开关控制 —
     * 解锁时 hexapod_update 才开启供电并输出 PWM。 */
    hal_debug_printf("Boot OK. Servo power OFF — waiting for ARM switch.\r\n");

    /* 启动提示音 — 提前到初始化之前 (有声 = Pico/电源/蜂鸣器正常):
     * 若下方初始化卡死, 看门狗复位后会再次响起 —
     * 间隔重复的提示音 = 初始化阶段反复挂起 (先查 I2C) */
    uint16_t startup_notes[] = {1000, 1500, 2000};
    uint16_t startup_durations[] = {100, 100, 200};
    hal_play_sound(3, startup_notes, startup_durations);

    /* 硬件看门狗 — 提前到初始化之前启用 (启动阶段 5s):
     * I2C 总线若被拉死 (器件损坏/总线短路), 阻塞式读写曾永久挂起
     * (2026-08 电压尖峰事件实况: 无提示音、无看门狗、无声死机)。
     * 现在 I2C 操作带 5ms 超时 (hexapod_i2c_protocol.h), 加上此处
     * 看门狗兜底, 任何启动阶段死锁都会自动复位重试。 */
    watchdog_enable(5000, 1);
    hal_debug_printf("Watchdog enabled (boot phase: 5000ms)\r\n");

    /* 机器人初始化 (PCA9685 I2C 检测不受舵机供电影响, 逻辑侧 3.3V) */
    if (!robot_init()) {
        /* 初始化失败: 红灯闪烁, 但保持 USB 命令可用 (如 !I2C 诊断) */
        hal_debug_printf("Robot init failed! Use !I2C to check bus, !P to test servos.\r\n");
        while(1) {
            watchdog_update();  /* 喂狗: 保持本诊断循环存活 (不被 5s 看门狗复位) */
            hal_poll_usb_commands(NULL);
            hal_led_blink(1, 2);
            sleep_ms(500);
        }
    }

    /* 把机器人实例交给 HAL: !HO (网页校准页设中心) 要直接写 leg_configs 里的
     * horn_offset, IK 每周期现读该结构体, 写完下一拍即生效 */
    hal_calib_bind_robot(&g_robot);

    /* 非易失校准: 加载并覆盖运行时配置
     * (舵机供电未开, 此时写入 PWM 周期无实际输出, 时序安全) */
    if (store_load()) {
        /* 返回实际套用的舵机数: 部分校准的记录只覆盖已调过的腿, 打完计数
         * 一眼能看出"到底吃进去几路", 不用去猜 done_mask */
        uint8_t n_cal = store_apply_to_robot(&g_robot);
        hal_debug_printf("[STORE] Calibration loaded from flash (%u/18 servos + periods)\r\n",
                         (unsigned)n_cal);
    } else {
        hal_debug_printf("[STORE] No valid calibration - using hexapod_config.h defaults\r\n");
    }
    store_flush_pending(true);

    /* 初始化完成 → 看门狗收紧到主循环超时 */
    watchdog_enable(1500, 1);
    hal_debug_printf("Watchdog rearmed (main loop: 1500ms)\r\n");

    /* 硬件信息打印 */
    hal_debug_printf("\r\n");
    hal_debug_printf("Servo: PCA9685 x2 via I2C (GP14/GP15)\r\n");
#if INPUT_CONTROL_MODE == 0
    hal_debug_printf("Input: CRSF (ELRS) via UART1 (GP4/GP5) @420000 baud\r\n");
#elif INPUT_CONTROL_MODE == 1
    hal_debug_printf("Input: PS2 gamepad via bit-bang SPI (GP6~GP9)\r\n");
#else
    hal_debug_printf("Input: USB CDC Serial (no UART1 required)\r\n");
#endif
    hal_debug_printf("Battery: ADC2 (GP28, divider 47/377)\r\n");
    hal_debug_printf("Buzzer: GP13 (passive, PWM)\r\n");
    hal_debug_printf("LED: GP25 green (status), GP12 red (alarm)\r\n");
    hal_debug_printf("DC Motor: GP2/GP3 (PWM)\r\n");
    hal_debug_printf("Servo Power: GP10 left, GP11 right\r\n");
    hal_debug_printf("Debug: USB CDC\r\n");

#if INPUT_CONTROL_MODE == 0
    /* 打印 CRSF 摇杆映射 */
    hal_debug_printf("\r\nCRSF Channel Mapping:\r\n");
    hal_debug_printf("  Normal mode (CH8=LOW):\r\n");
    hal_debug_printf("    CH1 (Ail): Strafe    CH2 (Ele): Forward\r\n");
    hal_debug_printf("    CH3 (Thr): Height    CH4 (Rud): Turn\r\n");
    hal_debug_printf("  Balance mode (CH8=HIGH):\r\n");
    hal_debug_printf("    CH1 (Ail): Roll      CH2 (Ele): Pitch\r\n");
    hal_debug_printf("    CH3 (Thr): Height    CH4 (Rud): Yaw\r\n");
    hal_debug_printf("  Switches:\r\n");
    hal_debug_printf("    CH5 (SWA): Arm    CH6 (SWB): Gait\r\n");
    hal_debug_printf("    CH7 (SWC): Speed  CH8 (SWD): Balance\r\n");

    hal_debug_printf("\r\nWaiting for ELRS link...\r\n");
#elif INPUT_CONTROL_MODE == 1
    /* 打印 PS2 摇杆映射 */
    hal_debug_printf("\r\nPS2 Control Mapping:\r\n");
    hal_debug_printf("  L-Stick: Forward/Strafe    R-Stick: Turn/Height\r\n");
    hal_debug_printf("  START: Arm   SELECT: Balance   L1/R1: Gait   D-Pad: Stance\r\n");
    hal_debug_printf("  Circle: Emergency Stop   !MODE crsf|ps2: input switch\r\n");
    hal_debug_printf("\r\nWaiting for PS2 controller...\r\n");
#else
    hal_debug_printf("\r\nUSB Serial Commands:\r\n");
    hal_debug_printf("  Movement: !F !B !L !R !Q !E !S\r\n");
    hal_debug_printf("  State:   !O(arm) !G<n>(gait) !T(balance) !U/!D(lift)\r\n");
    hal_debug_printf("  Servo:   !P<id> <angle> !W<id> !Z !A\r\n");
    hal_debug_printf("  Calib:   !C[<id>] !+/- !N !D\r\n");
    hal_debug_printf("\r\nReady for USB commands.\r\n");
#endif
    hal_debug_printf("Send '!V' to toggle debug level (current=%u), '!VER' for version\r\n",
                     hal_debug_get_level());

    /* 主循环 */
    uint32_t last_status_time = 0;
    uint32_t last_debug_time  = 0;
    uint32_t last_ch_telem_time = 0;
    uint32_t last_update      = 0;
    uint32_t frame_delta_total = 0;
    uint32_t last_battery_check = 0;
    bool     servo_power_cut    = false;   /* 舵机供电是否已被过放/过压保护切断 */

    while (1) {
        watchdog_update();
        uint32_t now = to_ms_since_boot(get_absolute_time());

        /* ---- 每20ms控制循环 ---- */
        if (now - last_update >= CONTROL_LOOP_PERIOD_MS) {
            hal_input_sync_mode();   /* 输入源跟随 input_mode 参数 (网页滑条也即时生效) */
            hexapod_update(&g_robot);
            hal_periph_poll();       /* 外设使能/波特率/I2C 模式跟随参数 + UART0 收行转发 */
            last_update = now;

            /* 事件日志回写: 仅在安全上下文刷入 flash。行走中页编程关中断
             * ~1-3ms 会导致 CRSF (420000 baud, 32B FIFO) 丢帧, 故仅缓冲。 */
            store_flush_pending(!g_robot.state.robot_on ||
                                hal_is_calibration_active() ||
                                hal_is_period_calib_active());

#if INPUT_CONTROL_MODE == 0
            /* 统计 CRSF 帧到达数 */
            if (hal_debug_get_level() >= 1) {
                frame_delta_total += hal_debug_get_crsf_frame_delta();
            }
#endif
        }

        /* ---- 分级调试输出 ---- */
        if (hal_debug_get_level() >= 1 && (now - last_debug_time >= DEBUG_PRINT_INTERVAL_MS)) {
            last_debug_time = now;

#if INPUT_CONTROL_MODE == 0
            /* Level 1: CRSF 接收器原始数据 */
            const crsf_state_t *crsf = (const crsf_state_t *)hal_debug_get_crsf_state();
            debug_print_crsf(crsf);
#endif

            /* Level 2: 控制量映射 */
            if (hal_debug_get_level() >= 2) {
                const control_state_t *state = hexapod_get_state(&g_robot);
                debug_print_control(state);
            }

            /* Level 3: 舵机输出 */
            if (hal_debug_get_level() >= 3) {
                debug_print_ik_angles();
            }

#if INPUT_CONTROL_MODE == 0
            /* CRSF 帧率统计 */
            hal_debug_printf("[DBG] FPS:%lu LVL:%u\r\n",
                        frame_delta_total * 1000 / DEBUG_PRINT_INTERVAL_MS,
                        hal_debug_get_level());
            frame_delta_total = 0;
#endif
        }

        /* ---- 每2秒运行状态摘要 ---- */
        if (now - last_status_time >= 2000) {
            last_status_time = now;
            const control_state_t *state = hexapod_get_state(&g_robot);

            /* 尾部 Bal/St/Hi 是网页「模式」页的实时状态源:
             * Bal=平衡模式, St=站立姿态(-1/0/+1), Hi=高度积分开关。
             * 格式改动要同步 server.py 的 RE_RUN_MODE 与 test_webconfig.py。 */
            if (state->robot_on) {
                hal_debug_printf("[RUN] Travel X:%d Y:%d Z:%d Gait:%d Lift:%d Bal:%d St:%d Hi:%d\r\n",
                            state->travel_length.x,
                            state->travel_length.y,
                            state->travel_length.z,
                            state->gait_type,
                            state->leg_lift_height,
                            state->balance_mode ? 1 : 0,
                            state->stance_mode,
                            (int)HEIGHT_INTEGRATE);
                if (LED_HEARTBEAT_ENABLED) hal_led_set(0, true);
            } else {
#if INPUT_CONTROL_MODE == 2
                hal_debug_printf("[IDLE] Send !O to arm, !F/!B/!L/!R to move Bal:%d St:%d Hi:%d\r\n",
                            state->balance_mode ? 1 : 0, state->stance_mode, (int)HEIGHT_INTEGRATE);
#else
                /* 输入源是运行期选择 (!MODE), 文案要跟着当前源走 */
                if (hal_input_is_ps2()) {
                    hal_debug_printf("[IDLE] Waiting for START (PS2 arm)... Bal:%d St:%d Hi:%d\r\n",
                            state->balance_mode ? 1 : 0, state->stance_mode, (int)HEIGHT_INTEGRATE);
                } else {
                    /* 解锁通道可改配 (模式矩阵), 文案不写死 CH5 */
                    hal_debug_printf("[IDLE] Waiting for Arm signal... Bal:%d St:%d Hi:%d\r\n",
                            state->balance_mode ? 1 : 0, state->stance_mode, (int)HEIGHT_INTEGRATE);
                }
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

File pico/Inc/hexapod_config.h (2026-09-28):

/**
 * @file hexapod_config.h
 * @brief 六足机器人配置文件
 * @note 用户应根据实际机器人参数修改此文件
 *
 * ★ 两类参数, 改法不同:
 *
 *   1. 硬件/机械常量 (引脚、舵机 ID 映射、舵机软限位、舵盘偏移)
 *      —— 直接改下面的数字。改了要重新编译烧录。
 *
 *   2. 运行时可调参数 (电池阈值、步长、死区、方向取反、功能开关、
 *      几何量: 腿节长度/安装角/足端坐标/舵机零位…)
 *      —— 形如 `#define X (g_params.x)`, 实际值存在 RAM 里, 可用
 *          !CFG / !CFGR / !CFGW 串口改, 或在网页 Configurator 里拖滑块。
 *          它们各自的默认值写在同一行的 `X_DEFAULT` 宏里 ——
 *          换板/换机架时改那个值即可, 复位后即为新默认。
 *          详见 hexapod_params.h。
 *
 *   两类都以 `_DEFAULT` 结尾的宏 = 上面第 2 类的"出厂默认值"。
 *
 * ★ 几何参数 (geo 组) 只在上电时应用: params_load → robot_init 构造
 *   腿部配置。运行中改不重算 (平衡旋转/站姿缩放正在改写那些字段),
 *   改完重启生效 —— 但不必重新烧录。
 */

#ifndef HEXAPOD_CONFIG_H
#define HEXAPOD_CONFIG_H

#include "hexapod_types.h"
#include "hexapod_params.h"   /* 运行时参数实体 g_params (见文件头说明) */

/* ==================== 固件标识 ==================== */

/* 固件版本 (横幅 + !VER + 网页开始页显示), 取自构建时生成的 hexapod_version.h
 * (git describe: 打 tag 处 = "v0.4.0", tag 之后 = "v0.3.0-16-g8f5b04f", 工作区
 * 有未提交改动再加 "-dirty")。版本历史只存在于 git tag, 不手工维护第二个号。
 * 不在 CMake 构建里编译时 (无生成头) 退化为 unknown。 */
#if __has_include("hexapod_version.h")
#include "hexapod_version.h"
#else
#define HEXAPOD_FW_VERSION "unknown"
#endif

/* 硬件版本 (PCB 版次, 随 [VER] 应答一起报出, 显示在网页开始页/状态栏)。
 * 换板/改板时手工改这一处并重新编译 —— 版次只在 hardware/README.md 与这里维护。
 * 与固件版本的区别: 固件版本是"板上跑的哪次编译", 硬件版本是"跑在哪版板子上",
 * 两者组合才能判定"这个现象是固件引入的还是这批板子特有的"。 */
#define HEXAPOD_HW_VERSION "PCB v2"

/* ==================== 机械参数配置 ==================== */

/*
 * 坐标系统 (右手定则)：
 *
 *          Z+ (右)
 *          │
 *     LF   │   RF      机身俯视图，机头朝 X+
 *      ╲   │   ╱
 *    LM ───○─── RM      ○ = 机身几何中心 (原点)
 *      ╱   │   ╲
 *     LR   │   RR
 *          │
 *          └────── X+ (前)
 *
 *   Y+ = 垂直向上 (机身抬升方向)
 *
 * 每条腿 3 个关节，从机身向外依次为：
 *   Coxa (基节) → 水平旋转，绕 Y 轴
 *   Femur (股节) → 垂直旋转，绕 Z 轴
 *   Tibia (胫节) → 垂直旋转，绕 Z 轴
 */

/* ---- 腿节长度 (mm) ----
 * 从关节转轴中心到下一个关节转轴中心的直线距离。
 * 用量具实测，精确到 mm。
 *
 *   机身 ──[Coxa: 水平]──[Femur: 竖直]──[Tibia: 竖直]── 足端
 *          ←─ L_coxa ─→←── L_femur ──→←── L_tibia ──→
 *
 * ★ 运行时可改 (网页「几何」页, 重启生效): 六腿同值, 不镜像。 */
#define LEG_COXA_LENGTH_DEFAULT     45
#define LEG_FEMUR_LENGTH_DEFAULT    75
#define LEG_TIBIA_LENGTH_DEFAULT    120
#define LEG_COXA_LENGTH     ((uint16_t)(g_params.leg_coxa_mm))
#define LEG_FEMUR_LENGTH    ((uint16_t)(g_params.leg_femur_mm))
#define LEG_TIBIA_LENGTH    ((uint16_t)(g_params.leg_tibia_mm))

/* ---- 舵机零位参考 (0.1度单位) ----
 *
 * 这两个参数将 IK 几何角度映射为舵机输出。
 * 设定为使「所有舵机 0° = 站立姿态(足端刚好触地)」。
 *
 * 公式: femure_servo  = (angle_a1 + angle_a2) - FEMUR_SERVO_ZERO
 *       tibia_servo   = TIBIA_SERVO_ZERO - acos(膝角余弦)
 *
 * 你的硬件站立几何:
 *   ik_feet=137mm, pos_y=31mm, ik_a≈140.5mm
 *   femur_total = α_2 - α_1 (股节在足端线上方)
 *               = acos((75²+140.5²-120²)/(2×75×140.5)) - atan4(31,137)
 *               ≈ 58.7° - 12.7° = 46.0°
 *   → FEMUR_SERVO_ZERO = 450 (舵机0°→股节45°, 差1°在horn_offset补)
 *   膝角 = acos((75²+120²-140.5²)/(2×75×120)) ≈ 89.1° → TIBIA_SERVO_ZERO = 900
 *
 * ★ 运行时可改 (网页「几何」页, 重启生效): 六腿同值 —— 零位在左右取反
 *   之前应用, 所以一侧一个标量即可, 与安装角不同不镜像。
 *   改动前是编译期常量, IK 直接读宏 (hexapod_ik.c), 参数化后无需改 IK。 */
#define FEMUR_SERVO_ZERO_DEFAULT    450
#define TIBIA_SERVO_ZERO_DEFAULT    900
#define FEMUR_SERVO_ZERO    (g_params.femur_servo_zero)   /* 舵机0° → 股节离垂直45° = 离水平45° */
#define TIBIA_SERVO_ZERO    (g_params.tibia_servo_zero)   /* 舵机0° → 膝角90° */

/* ==================== 安全配置 ==================== */

/* 电池电压保护总开关：设为 1 启用，设为 0 完全禁用
 * 此开关统一控制三处电压保护:
 *   1. 上电启动检测 (hexapod_pico.c) — 电压异常拒绝舵机供电
 *   2. 运行电压监测 (hexapod_pico.c) — 每 1s 分级报警/断电
 *   3. 核心循环检查 (hexapod_core.c) — 紧急停止
 * 设为 0 时: 跳过 ADC 读取, 舵机供电无条件开启, 无任何电压报警。
 * ⚠️ 新 PCB (2026-08) 已将 ADC 改至 GP28 (绕开旧板损坏的 GP26) +
 *   VBAT 入口 TVS + ADC 输入齐纳钳位。
 * ★ 运行时可改: !CFG batt_check 1 /  网页「参数 → 功能开关」 */
#define BATTERY_CHECK_ENABLED_DEFAULT   0   /* ★ 待新 PCB 实测分压电路后启用 */
#define BATTERY_CHECK_ENABLED           (g_params.batt_check)

/* ==================== 电池检测配置 (GP28 ADC2, 2S 18650) ==================== */

/* 分压电阻: R1=330kΩ (电池+), R2=47kΩ (地), ADC 抽头在 R2
 *   (新 PCB 2026-08 由 100k+15k 改来: 串阻提高到 330k, 电压尖峰时
 *    流入 ADC 的电流被进一步限制, 与齐纳钳位配合更安全)
 * ADC 电压 = 电池电压 × R2/(R1+R2) = 电池 × 47/377
 * → 电池电压 = ADC 电压 × 377/47 ≈ 8.02×
 * 电池 8.4V (满) → ADC 1.05V;  6.6V (空) → ADC 0.82V  (安全范围)
 * 新 PCB (2026-08): 电池 ADC 从 GP26 改至 GP28 (ADC2),
 *   顺带绕开旧板被电压尖峰损坏的 GP26 ADC 通道 (见 STATUS 事件 3) */
#define BATTERY_ADC_PIN         28
#define BATTERY_ADC_INPUT       2
#define ADC_REF_VOLTAGE         3300
#define ADC_RESOLUTION          4095
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

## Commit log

2026-06-02 add test python and fix several bugs
    [hexapod_config.h, hexapod_core.c, hexapod_core.h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]
2026-06-03 fix the direction is wrong in balance mode
    [hexapod_config.h, hexapod_core.h, hexapod_i2c_protocol.c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]
2026-06-06 fix yaw movement bug
    [hexapod_config.h, hexapod_core.c, hexapod_core.h]
2026-06-06 fix yaw movement bug again
    [hexapod_core.c]
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2026-06-18 fix an issue where the usb serial port function is not working correcty
    [hexapod_config.h, hexapod_core.c, hexapod_hal_pico.c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]
2026-06-18 add hardware watchdog + I2C bus recovery, update STATUS.md
    - RP2040 hardware watchdog (1500ms timeout) to auto-reset on any hang
    - I2C bus recovery (I2C spec 3.1.16): 9 SCL pulses to release stuck SDA
    - Auto-trigger after 3 consecutive I2C write failures in hal_servo_flush
    - STATUS.md: document watchdog/I2C recovery, ESD incident, circuit protection guide
    [hexapod_hal_pico.c, hexapod_i2c_protocol.c, hexapod_i2c_protocol.h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]
2026-06-23 fix the codes in usb serial control mode and add a python script to adjust every servos‘ angle easliy
    [hexapod_config.h]
2026-06-23 burned out a second pico board!!But identified and resolved the issue,and added a detailed description of the problem
    [hexapod_config.h, hexapod_i2c_protocol.c, hexapod_i2c_protocol.h]
2026-06-27 feat: CH7 stance control + serial console fix + CH6 gait remap
    CH7 站立姿态三段开关 (窄80%/正常100%/宽120%):
    - hexapod_core: hexapod_apply_stance() 逐周期插值 + lift-gate
    静止时不动腿，行走时仅抬起的腿逐步挪位 (限2mm/周期)
    - hexapod_types: 新增 stance_mode/current_stance_scale/orig_init_pos
    - hexapod_config: STANCE_SCALE_NARROW/NORMAL/WIDE, STANCE_DEFAULT_MODE,
    STANCE_TRANSITION_SPEED, STANCE_MAX_STEP_MM
    - hexapod_crsf: CH7 map_to_3pos → stance_mode
    - hexapod_hal_pico: !M <-1/0/1> 串口命令
    CH6 步态三段开关重映射:
    - 低位: TRIPOD_6, 中位: TRIPOD_8, 高位: WAVE_24
    horn_offset 校准机制 (invert 后叠加, 每关节独立)
    ser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
    [hexapod_config.h, hexapod_core.c, hexapod_core.h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]
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2026-06-27 Fix release workflow: replace broken pico-sdk action with apt toolchain + SDK fetch
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2026-08-14 Sync firmware with final PCB layout: power management, channel remap and diagnostics
    Hardware sync:
    - Servo power control GP10 (left) / GP11 (right), default off, enabled
    only after battery check passes
    - Battery protection: 15/115 divider (2S 18650), overvoltage cutoff at
    8.8V (red LED + buzzer + servo power cut), undervoltage cutoff at 6.6V,
    warning 7.0V, recovery 7.3V; boot-time check before servo power-up
    (temporarily disabled via BATTERY_CHECK_ENABLED=0 while the ADC divider
    is being debugged)
    - DC motor PWM GP2/GP3 (10kHz), red alarm LED GP12, passive buzzer GP13
    (PWM tone generation with fixed missing slice enable)
    Servo mapping:
    - PCB board addresses: 0x40 = left legs (I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
    [hexapod_config.h, hexapod_core.c, hexapod_core.h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]
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2026-08-14 Fix !PER calibration: center pulse, horn offset switch, remove !PWR
    - Fix coxa target pulse: pca9685_angle_to_pulse(900) clamps to the 2500us
    limit; center position must use angle 0 (1500us). Print per-write result
    (N/6 OK) for visibility
    - Add !PERO 0/1 switch: optionally add each leg's coxa_horn_offset from
    the config (default ON, matching the runtime formula IK + horn_offset);
    OFF sends the raw 1500us center to all coxas
    - Remove !PWR diagnostic command: servo power layer confirmed working via
    CRSF flight testing
    - Update PWM_PERIOD_US_BOARD0/1 to 9500 after board measurement
    [hexapod_hal_pico.c, hexapod_i2c_protocol.h]
2026-08-15 IMU: boot recovery, INT diagnostics, upside-down mount mapping
    Hardware control:
    - BOOT pin (GP27): drive high at startup for normal application boot;
    on I2C init failure automatically cycle the pin (low 50ms -> release
    -> POR wait) and retry up to 3 times
    - INT pin (GP28): BSX data-ready interrupt config (INT_MSK/INT_EN/CNTL
    in bno055 init) + dual-edge GPIO IRQ flag gating hal_imu_read, with
    50ms timeout fallback to polling so compensation never stalls
    - !IMU debug command: availability, INT rate/pin level, INT_STA, config
    readback, SW rev, calibration, last angles
    Diagnostics findings on this board:
    - BNO055 SW rev 0x0308 predates BSX DRDY interrupt support (>= 0x0314):
    INT_ST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
    [bno055.c, bno055.h, hexapod_config.h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]
2026-08-15 Fix the wrong settings of imu Changes the logic what ARMED do And add some new idea in two md for future use
    [hexapod_config.h, hexapod_core.c, hexapod_hal_pico.c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]
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2026-08-22 Harden I2C and boot path: timeouts, early beep, early watchdog
    - Root cause of the silent boot hang: PCA9685_I2C_TIMEOUT_US was defined
    but never used, so a stuck I2C bus blocked robot_init forever before
    the beep/watchdog ran. All blocking I2C ops now use the _until
    variants with a 5ms timeout (PCA9685, BNO055).
    - Move the startup beep and hardware watchdog before robot_init
    (5s boot phase, tightened to 1.5s for the main loop); any init
    deadlock now resets instead of hanging silently, and repeated beeps
    mean repeated init hangs (check I2C first).
    - Remove unused BNO055 INT register writes from init.
    - Note: hexapod_pico.c also carries the default gait change to
    GAIT_TRIPOD_6 a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
    [bno055.c, hexapod_i2c_protocol.c, hexapod_i2c_protocol.h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]
2026-08-22 Make INPUT_CONTROL_MODE a compile-time 3-way choice with USB debug switch
    - INPUT_CONTROL_MODE: 0=CRSF, 1=PS2, 2=USB (single-input assumption,
    nobody runs two radios). PS2_ENABLED and USB_DEBUG_ENABLED are
    auto-derived from it; both radio drivers are always compiled in
    radio modes so !MODE crsf|ps2 switches inputs at runtime without
    rewiring the board.
    - USB debug console and USB host-data mode are now mutually exclusive:
    INPUT_CONTROL_MODE=2 silences all debug output (hal_debug_printf)
    and keeps the CDC channel clean for the host protocol.
    - Remove INPUT_TYPE_AUTO auto-detection plumbing from input init.
    - Add PS2-specific macros: per-axis direction inverts, height deadzone,
    e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
    [hexapod_config.h, hexapod_core.c]
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2026-08-22 Add !PS2DBG observe mode and fix PS2 state print handling
    - !PS2DBG toggles a 1Hz observe mode printing all PS2 channels while
    the robot ignores controller input; fix its parser condition, which
    matched wrong buffer indices and fell through to the servo command
    handler.
    - Fix the Pressed line being wiped by the console's line-clear when a
    USB packet split left it without a newline; print "(none)" when no
    button is held.
    - Remove Triangle debug-level cycling (serial !V remains the only way
    to change debug level).
    - Note: file also carries input-init rework (CRSF UART always on in
    radio modes), hal_debug_printf gating by USB_DEBUG_ENABLED, and the
    !I2C bus-idle diagnostic.
    Co-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
    [hexapod_hal_pico.c]
2026-08-22 serial_console.py: auto-detect, auto-reconnect, queued commands
    - Continuously scan for ports (by-id Pico preferred, then ttyACM*),
    connect as soon as a device appears, reconnect on loss without
    exiting - start the script before powering the robot to capture the
    full boot log.
    - Queue commands typed while disconnected and flush them on connect.
    - Detect port-node disappearance mid-session, report open errors
    distinctly (no device vs open failure).
2026-08-22 Update docs: PS2 remap, input modes, protection design, events
    - README: new PS2 stick/button mapping (LX=yaw, LY=integral height,
    RX=strafe, RY=forward), D-Pad gait/stance, !PS2DBG, !MODE switching,
    serial console auto-connect notes.
    - STATUS: next-PCB pin plan draft, I2C cascade failure and power
    protection design, boot-phase I2C hang hardening record, IMU mount
    position analysis, voltage-spike event log.
2026-08-27 Sync firmware to new PCB: pins, IMU mounting, safer battery divider
    - IMU: normal mounting on new PCB, drop -180 flip compensation
    in hal_imu_read (axis mapping unchanged)
    - IMU BOOT GP27->GP22; battery ADC GP26->GP28 (ADC2)
    - Battery divider 100k+15k -> 330k+47k (47/377, limits spike
    current into ADC)
    - README/STATUS: describe current state only; remove change logs,
    completed checklists and the pin-change plan section
    [hexapod_config.h, hexapod_hal_pico.c, hexapod_pico.c]
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2026-09-10 Add clickable BOM and reader-focused hardware README
    - bom/hexapod_bom.md: project-wide BOM with clickable purchase
    links (CSV stores URLs as plain text; xlsx kept local as the
    editing source)
    - tools/xlsx_bom_to_csv.py: extracts hyperlink targets from xlsx,
    trims trailing empty columns, generates CSV + markdown table
    - hardware/README.md: rewritten for readers - file inventory,
    design highlights, missing-items list; author-only conventions
    and export guide removed (available in git history)
    [hexapod_bom.csv]
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2026-09-15 Add flash storage: calibration persistence + event log
    Servo calibration (horn offsets, PWM periods) previously had to be
    copied back into hexapod_config.h and reflashed after every session.
    Now !SAVE writes it to a flash sector and it is loaded and applied at
    boot; an event log sector records boot/battery/calibration events.
    Write paths are RAM-resident (__no_inline_not_in_flash_func) and feed
    the watchdog by writing the LOAD register directly, since
    watchdog_update() lives in flash and cannot be called while XIP is
    stalled. CRC32 is bitwise rather than table-driven for the same reason.
    Log events buffer in RAM while walking and flush only when the robot is
    stationary, since a 1-3ms page p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
    [hexapod_hal_pico.c, hexapod_pico.c, hexapod_store.c]
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2026-09-16 Remove dead config params and fix stale comments
    DEFAULT_INIT_Y was unreachable: its only user,
    hexapod_adjust_to_body_height(), had no call sites. Body height is
    applied in the IK layer (ik.c: relative_pos.y = target_foot.y +
    body_pos.y), not via init_pos_y. Also drops MIN_VOLTAGE_MV and
    LIFT_SPEED_MM_PER_TICK (both zero-referenced), and the 12
    SERVO_*_FEMUR/_TIBIA macros -- servos are addressed as leg*3+joint,
    so only the 6 SERVO_*_COXA (used by the !PER calibration list) are
    kept.
    Also fixes comments that contradicted the code:
    - hal_get_servo_id(): PCA9685 board addresses were swapped
    (0~8 is on 0x41 and 9~17 on 0x40, not the reverse)
    - hexapod_config.h: init_pos_y formula, and BODY_H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
    [hexapod_config.h, hexapod_core.c, hexapod_core.h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]
2026-09-27 Feed the watchdog during the !W sweep
    !W steps one servo 300->1500->300 with 80ms delays, about 3.8s end
    to end -- well past the 1.5s watchdog the main loop enables. The
    board reset mid-sweep, and the symptom ("the sweep restarts halfway")
    reads like a servo or supply problem rather than a watchdog timeout,
    so feed the dog inside both delay loops.
    [hexapod_hal_pico.c]
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2026-09-27 Make IMU compensation switchable at runtime
    IMU_ENABLED was folded into #if blocks at every use site, so trying the
    robot without compensation -- or with it -- meant a rebuild and a
    reflash. The sites become runtime checks of g_params.imu_enabled, and
    hal_imu_init()/hal_imu_read() report "not available" / "invalid" when it
    is off, so callers in core.c keep their existing shape.
    The compensation gain and the roll/pitch signs are runtime parameters
    too: getting the polarity wrong shows up as the leveling making the
    tilt worse, and that is a two-second experiment with !CFG
    imu_roll_sign / imu_pitch_sign instead of a flash cycle.
    Enabling at runtime only takes effect on the next read (the sens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
    [hexapod_config.h, hexapod_core.c, hexapod_hal_pico.c]
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2026-09-27 Add [CH] channel telemetry and remappable CRSF channels
    Nothing in the firmware said which channel did what, and the channel
    assignment was a compile-time macro, so changing radios or reordering
    channels in the transmitter meant editing config.h. The eight
    CRSF_CHANNEL_* macros now redirect to runtime parameters
    (crsf_ch_fwd / crsf_ch_str / crsf_ch_turn / crsf_ch_hgt / crsf_ch_arm /
    crsf_ch_gait / crsf_ch_stance / crsf_ch_bal, 0-15 = CH1-CH16), so the
    assignment is editable from the console or the web UI, and directions
    stay per-function (flip inv_* after moving a channel, not the channel
    number).
    hal_debug_print_channel_telemetry() emits a [CH] line at 5Hz, driven
    from the main loop and in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
    [hexapod_config.h, hexapod_hal_pico.c, hexapod_pico.c]
2026-09-27 Control the reserved onboard peripherals from the console and web UI
    The board carries interfaces that were soldered but unused: two DC
    motors (GP2/GP3, PWM only -- no direction pins on this revision), the
    buzzer (GP13), both LEDs (GP25/GP12), a second UART on GP0/GP1, GP26/27
    as either an I2C bus or two ADC inputs, and the 14 PCA9685 channels no
    servo uses. They are now reachable as !MOTOR / !LED / !BUZZ / !UART0T /
    !I2C2 / !ADC2 / !PWM (with !PWMQ, !PWMOFF and a !PERIPH status dump),
    plus a web page for each group.
    Semantics are "test tool", which the docs state: the values live in RAM
    and never persist. Enabling a motor at the last duty cycle on power-up
    is a thing that can hurt someone,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
    [hexapod_hal_pico.c, hexapod_pico.c]
2026-09-27 Add "!I2C q" for dashboard polling, keep the full scan manual
    The web UI wants a quick bus health check on a timer, but !I2C also runs
    a 128-address scan. The scan happens inside the 20ms control loop
    (commands are handled from hal_input_update), so its cost is time the
    servos are not being updated: about 20ms on a healthy bus, but when the
    bus is stuck every I2C transaction burns PCA9685_I2C_TIMEOUT_US and 128
    addresses add up to 640ms of worst case. !I2C q does the targeted check
    only and the full scan stays a manual command.
    [hexapod_hal_pico.c]
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2026-09-27 Report the firmware version on boot and via "!VER"
    There was no way to tell which build is actually running on the board: the boot
    banner named the robot but carried no version, and "!V" only cycles the debug
    level, so "did my flash take?" had to be answered by guessing at behaviour. The
    web configurator's start page needs to answer it directly.
    Take the version from git describe (tag, commits since it, short hash, and a
    "-dirty" suffix for uncommitted trees) rather than maintaining a second number:
    the release history already lives in the annotated tags, and the hand-written
    pico_set_program_version had long since drifted from them. Generate the header
    from a custom target so it is re-eval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
    [hexapod_config.h, hexapod_hal_pico.c, hexapod_pico.c]
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2026-09-27 Add a start page between the browser and the debug UI
    Opening the configurator used to drop straight into the debug page even
    with nothing plugged in: every parameter slider and the command box were
    live. Now the page opens on a start page that only reports hardware
    state (web service, serial bridge, robot) and the firmware card, with a
    single "connect" button that stays disabled until the bridge and the
    device are both up. Parameter editing lives behind that button.
    The gate that matters is server-side (previous commit); the page just
    follows it:
    - #welcome is a fixed full-screen card; the whole debug UI moved into
    #app, hidden by default. The flash overlay moved out of #app so the
    st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
    [test_webconfig.py]
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2026-09-27 Add a "!RC" radio gate so the debug page can take over
    The web debug page is about to grow buttons that power the servos and
    walk the robot. While those are in use the radio must not fight them:
    a bumped stick on the bench would otherwise overwrite whatever the page
    just commanded. "!RC 0" locks the radio out, "!RC 1" lets it back in.
    Locked does not mean unplugged: the pad/receiver keeps being polled and
    the remote page keeps showing live channels -- only the mapping step
    (ps2_to_control / crsf_to_control) is skipped, so USB commands have the
    robot to themselves. The CRSF link-loss auto-stop is skipped too, for
    the same reason: travel belongs to the debug page while locked.
    The lock is su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
    [hexapod_config.h, hexapod_hal_pico.c]
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2026-09-27 Let the browser hold the radio and read back the run state
    The debug page is meant to drive the robot itself, so /connect now takes
    a {"radio": bool} body: unchecked means the server sends "!RC 0" and
    keeps re-sending it every ~2s, so a firmware reset or a dropped line
    can't quietly hand control back to the transmitter (the firmware
    unlocks itself after 6s of silence). Disconnect, losing the device,
    losing the bridge and the last SSE subscriber leaving all release the
    lock; a bridge reconnect re-locks if the browser is still connected.
    Also parse the firmware's "[RC] locked|unlocked" and "[RUN]"/"[IDLE]"
    lines into rc/run frames (travel, gait and lift ride along with [RUN])
    so the page can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
    [server.py, test_webconfig.py]
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2026-09-27 Let one mode table serve both transmitters and make the geometry tunable
    PS2 and CRSF still wanted different setups for the same actions: the
    gamepad triggers its arm/balance keys on a rising edge, while a radio
    switch holds its channel high, so a configuration could not be carried
    between the two. Each row of the mode matrix and of the combo table now
    carries a "单击触发" checkbox -- checked means one press acts once
    (arm and balance flip on entry, gait and stance latch one selection),
    unchecked means the old level behaviour (hold to stay active). The bit
    lives above the existing payload: mode_* is now channel<<3 | levels |
    click<<8 (0..511) and combo_* is a | b<<5 | hold<<10 (0..2047),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
    [hexapod_config.h, hexapod_params.c, hexapod_ps2.c]
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2026-09-27 Add voltage and IMU calibration to the calibration page, align the click column
    The calibration page was servo-only, but two other things on this robot need
    calibrating and had nowhere to live. The mode page's "click trigger" checkbox
    was also drawn wrong: a mode row packed it into the same flex cell as the
    low/mid/high boxes, which overflows the 150px column, and a combo row handed
    four children to a three-column grid, which pushed the checkbox onto an
    implicit second row under the row label. Both row kinds now share a four
    column grid (label | channel or key A | levels or key B | click) with the
    checkbox as its own cell, so the two tables line up.
    Voltage calibration needs no new command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
    [bno055.c, bno055.h, hexapod_hal_pico.c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]
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2026-09-27 Declare the page state before the init calls that read it
    initCalibPage() renders the voltage card, which reads curParams, but the
    three state objects were declared further down the top-level script.
    const/let sit in the TDZ until their declaration, so that read threw
    ReferenceError (index.html:1764), everything after it never ran, and
    since connect() is the script's last line the page opened no connection
    at all -- it just sat on 「检测中…」. Browser cache had been hiding it.
    Move pRows/pBase/curParams above the init calls, and add a regression
    check that actually executes the page: load it in a headless browser and
    assert the status line is no longer the initial 「检测中…」.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
    [test_webconfig.py]
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2026-09-27 修复: 校准面板滑条发 "!P 0 300", 固件读成「舵机 0 → 角度 0」
    !P 的 id 必须紧跟命令字 —— 固件从 buf[2] 读 id、第一个空格后面读角度,
    "!P 3 300" 被解析成舵机 3 → 角度 3 (角度只吃到 id 的首位)。页面上不报错,
    表现是滑条拖了舵机几乎不动, 逐舵机定中心这条流程等于用不了。真机核对时才抓到。
    测试两头都钉住: 静态契约原来钉的是错的那串 (所以一直是绿的), 改成
    "!P${CAL.sel} ${v}"; [5] 探针里把面板真按一遍 (滑条 onchange / +20 / 设为中心)
    并捕获 sendCmd 拿到的原样命令串 —— 对老页面复现出 ['!P 3 300', ...],
    改完是 ['!P3 300', '!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
    [test_webconfig.py]
2026-09-27 修复: !I2C 读 MODE1 先写寄存器指针; !P 形状不对就打 Usage 拒绝
    两处都是"静默出错" — 现象看着像硬件/操作问题, 其实是代码在猜:
    - !I2C 的 PCA9685 检测直接 i2c_read, 没先写寄存器指针。I2C 读是从芯片内部
    指针处开始吐, 指针停在上次访问的位置 → 真机实测 MODE1 在 0xE0/0x00 之间漂
    还不能当"检测失败"看。改成先 write 0x00 (MODE1) 再读, 与 BNO055 那段一致;
    真机三读两块板都稳定 0x21 (AI|ALLCALL, 正是初始化写进去的值)。
    - !P 老解析从 buf[2] 直接读 id、再取第一个空格后的数当角度: "!P 0 300" 被读成
    "舵机 0 → 角度 0" (角度吃到的是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
    [hexapod_config.h, hexapod_hal_pico.c, test_webconfig.py]
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2026-09-28 修复: 直连态还显示「串口桥接」的隐藏失效, 以及 Pages 首次部署失败
    - 页面: 样式表加一条兜底 `[hidden]{display:none!important}` —— `hidden` 属性只在
    没人给同一元素写 display 时才管用, 而 `.row{display:flex}` 会盖掉浏览器默认的
    `[hidden]{display:none}`, 于是 `$("wel-row-bridge").hidden = true` 看着设了却没藏住:
    直连模式下开始页照样列出「串口桥接 (serial_console.py)」。之前那两处
    `.tabpage[hidden]` / `#welcome[hidden]` 是同一类问题的点状补丁, 这次补在根上
    - 测试: 直连态的隐藏按 `getComputedStyle().display` 校验 (桥接行/固件卡/桥接日志
    三处), 并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
    [test_webconfig.py]
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2026-09-28 修复: 发出去的固件报错版本号 (v0.4.0 的 uf2 里写的是 v0.3.0-56-g9be97c7)
    打开 release 里那个 uf2 核对时发现的: 里面嵌的版本串是 v0.3.0-56-g9be97c7, 不是
    v0.4.0 —— 而本地按同样条件 (annotated tag + 全历史) 编出来的是 v0.4.0。CI 里
    git describe 没认出刚推的 v0.4.0, 老 tag 在而新 tag 不在 (fetch-depth: 0 也没救
    回来, 原因没坐实: CI 日志要权限读不到)。这个串会显示在网页开始页与串口横幅上,
    是"板上跑的到底是不是刚发的这版"的凭据, 不能靠 CI 的 git 状态猜。
    改成发布工作流把正在发的 tag 明着传给构建 (-DHEXAPOD_FW_GIT_OVERRIDE=
    ${{ github.ref_name }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
    [test_webconfig.py]
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2026-09-28 固件: IMU 读加看门狗 (失败→总线恢复→重新初始化), 卡住不再静默
    现场 (2026-09-28 真机, v0.4.0): I2C 事务会整段卡住几秒到几分钟 —— !IMU 只剩
    available: + 冻结的 last:, 同一时刻 !I2C q 里两块 PCA9685 正常应答而 BNO055
    0x29 NOT FOUND、Bus idle SDA/SCL 都是 1 = **芯片不应答它自己的地址**, 既不是
    总线电气问题也不是外设卡死 (紧接着再问 !IMU 仍缺那八行, i2c_init 治不了它)。
    卡住期间控制回路 (姿态补偿) 的读也一并停, 而空闲时没有任何自恢复: 唯一的 I2C
    恢复挂在舵机 flush 的连续失败分支上, 它没有待写舵机时提前返回。
    看门狗挂在控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
    [hexapod_core.c, hexapod_hal_pico.c]
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2026-09-28 测试与文档: 看门狗/轮询速率的回归 + STATUS 记下卡死签名与开放问题
    425 项通过 0 失败 (原 416, 新增 9): 轮询间隔两边同值且 == 0.2、看门狗在控制回路
    与 !IMU 两处挂载、两级恢复 (总线恢复 → 重新初始化) 与计数、解锁态跳过重初始化、
    三处打印字符串齐全; raw 检查区分「有解析器的数据行不进日志」与「没人认领的杂项行
    照旧进日志」([P] WARN / [IMU] 警告同理)。四处反面对照 (页面退回 1s、server 白名单
    漏 imu、看门狗调用被删、打印串改坏) 各自命中预期检查, 文件按字节还原。
    STATUS 修正卡死签名: 芯片不应答自己的地址 (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
    [test_webconfig.py]
2026-09-28 网页/服务端: IMU 状态块整块折叠, 日志面板不再被 25 行/秒冲掉
    上一版把 !IMU 提到 5Hz 之后面板反而更吵了: 有解析器的数据行被 raw 白名单挡住,
    没解析器的杂项行 (表头 / INT_STA= / INT cfg readback: / SW rev: / 页脚) 5 行 ×
    5Hz = 25 行/秒, 600 行面板二十几秒就冲干净 (改动前是整块 12 行 × 1Hz)。折叠整块:
    `=== IMU Status ===` 到页脚之间的行不进日志面板。三条边界:
    - 只挡日志面板, 照常解析 —— folded 只进 raw 那条判断。挂在解析前就等于曲线
    没有数据 (页面全空, 且两边一起错时逐帧差分还照样绿)
    - 压噪不藏故障: 块内的 fail: 行 (连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
    [server.py]
2026-09-28 测试与文档: 折叠状态机单测 + 边界契约 + STATUS 记折叠语义
    437 项通过 0 失败 (原 425, 新增 12): 折叠状态机八个角 (块外不折/表头页脚自己也不
    显示/块内杂项折/块内 fail: 放行/页脚丢失按上限兜底), 两边常量同值, 与固件打印
    一字不差, 折叠只挂在 raw 判断上 (解析照走), 以及四条 raw 语义 (数据行不进/
    整块不进/块内 fail: 进/块外 [IMU] 警告进)。
    五处反面对照各自命中预期检查: 页面折叠挪到解析前 (探针炸)、server 折叠没挂 raw、
    块内不放行 fail:、表头改一个字符、固件表头改了网页没跟。注: server 侧的行为注入
    必须 reload 模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
    [test_webconfig.py]
2026-09-28 固件: !I2C 电平诊断不再扰动总线 (切引脚会锁死 I2C 外设)
    真机现场: 网页每 3s 的 !I2C q 轮询之后, 控制回路连丢约 200ms 读数, 日志刷
    [IMU] 读连续失败 … → 总线恢复 那一串。实测 (同一套网页轮询表):
    - 完整模仿 141s → 21 次卡死, 间隔恒为 3s 的整数倍 (= 轮询周期)
    - 零轮询 / 只轮询 !IMU 各 180s → 0 次
    - 23 次恢复里没有一次打印 "SDA stuck LOW, sending recovery clocks" → SDA 没被
    从设备拉死, 是外设卡不是器件卡; 且 !I2C q 自己的 0x28 地址 NACK 之后的 0x29
    探测还成功 → 坏在检测块末尾那段切引脚
    根因: 那段把 SDA/SCL 切成 GPIO_FUNC_SIO 再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
    [hexapod_hal_pico.c]
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
